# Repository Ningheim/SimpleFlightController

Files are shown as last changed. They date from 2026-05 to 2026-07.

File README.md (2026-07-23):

# SimpleFlightController



This is a USB-C powered 2-layer flight controller built around the STM32F722. It's 2S LiPo/Li-ion battery, a 6-axis IMU, a barometer, microSD logging, and two servo outputs.

## List of Materials

- MCU: STM32F722RET6
- IMU: ICM-20948 (SPI) — barometer: BME280 (I2C)
- Charger: BQ25887
- Power: TPS63070 buck-boost, LMR51430 buck
- microSD: 4-bit SD card slot
- J1/J3: servo/PWM headers
- J2: 2S battery screw terminal
- SW1 reset, SW2 boot, D1 status LED indicator
- 25MHz HSE + 32.768kHz LSE crystals
- Board: 50x55mm, 2-layer, KiCad 
- the hardware folder has the KiCad files. Run lcsc.py first to get parts KiCAD didn't have. This came from the hack club guide.

## Power architecture

```
2S Battery ----> TPS63070 ----> VSYS ----> LMR51430 ----> 3.3V rail

USB-C VBUS ----> BQ25887 Charger
```

## How To Make It Yourself

1. Run `lcsc.py` so the libraries resolve.
2. Open the .kicad_pro file in KiCad.
3. Export gerbers/drill/pick-and-place and send to JLCPCB for a quote.
4. Generate a BOM and assemble with a stencil, paste, and reflow.
5. Power up: 2S LIPO pack on the battery pad, `J2`.
6. Flash: hold `SW2`, reset with `SW1`, flash over `USB1`.

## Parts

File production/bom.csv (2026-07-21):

Designator | Footprint | Quantity | Value | LCSC Part #
C1, C18, C19, C20, C21, C26, C27, C28, C29, C30, C39 | 0402 | 11 | 100nF
C10, C11, C9 | 0805 | 3 | 22uF
C12, C13, C14, C3, C4, C6, C8 | 0402 | 7 | 10uF
C15 | 0402 | 1 | 2.2μF
C16, C17 | 0805 | 2 | 22μF
C2 | 0805 | 1 | 44uF
C22, C24 | 0402 | 2 | 100uF
C25 | 0402 | 1 | 2.2uF
C31, C32, C33, C34, C5 | 0402 | 5 | 1uF
C35, C36 | 0402 | 2 | 6.8pF
C37, C38 | 0402 | 2 | 20pF
C7 | 0805 | 1 | 47uF
CARD1 | TF-SMD_DM3CS-SF | 1 | DM3C-SF | C3177034
D1 | 0402 | 1 | LED
J1, J3 | PinHeader_2x03_P2.54mm_Vertical | 2 | Conn_01x03
J2 | TerminalBlock_Xinya_XY308-2.54-3P_1x03_P2.54mm_Horizontal | 1 | Screw_Terminal_01x03
L1 | 1008 | 1 | 1μH
L2 | L_APV_ANR4012 | 1 | 1.5μH
L3 | 1210 | 1 | 5.6μH
L4 | L0603 | 1 | FCM1608KF-601T03 | C141723
R1, R2 | 0201 | 2 | 5.1K
R10 | 0201 | 1 | 5.23k
R11 | 0201 | 1 | 383
R12 | 0201 | 1 | RCBSET
R13, R14, R15, R18, R19, R20, R21, R22, R23, R24, R4, R5, R6, R8 | 0201 | 14 | 10k
R16 | 0201 | 1 | 22.1k
R17 | 0201 | 1 | 100k
R3 | 0201 | 1 | 2.2k
R7 | 0201 | 1 | 300
R9 | 0201 | 1 | 30.1k
SW1, SW2 | SW-SMD_L3.9-W3.0-P4.45 | 2 | TS-1088-AR02016 | C720477
U1 | VQFN-15_L3.0-W2.5-P0.50-BL | 1 | TPS63070RNMR | C109322
U3 | QFN-24_L3.0-W3.0-P0.40-BL-EP | 1 | ICM-20948 | C726001
U4 | LGA-8_BME280_BL | 1 | BME280 | C92489
U5 | VQFN-24_L4.0-W4.0-P0.50-TL-EP2.7 | 1 | BQ25887RGET | C2862617
U6 | SOT-23-6_L2.9-W1.6-P0.95-LS2.8-BL | 1 | LMR51430XDDCR | C5185863
U7 | LQFP-64_10x10mm_P0.5mm | 1 | STM32F722RETx
USB1 | USB-C-SMD_TYPE-C-16PIN-2MD-073 | 1 | TYPE-C 16PIN 2MD | C2765186
X1 | CRYSTAL-SMD_4P-L3.2-W2.5-BL | 1 | X322525MOB4SI | C9006
X2 | FC-135R_L3.2-W1.5 | 1 | Q13FC1350000400 | C32346

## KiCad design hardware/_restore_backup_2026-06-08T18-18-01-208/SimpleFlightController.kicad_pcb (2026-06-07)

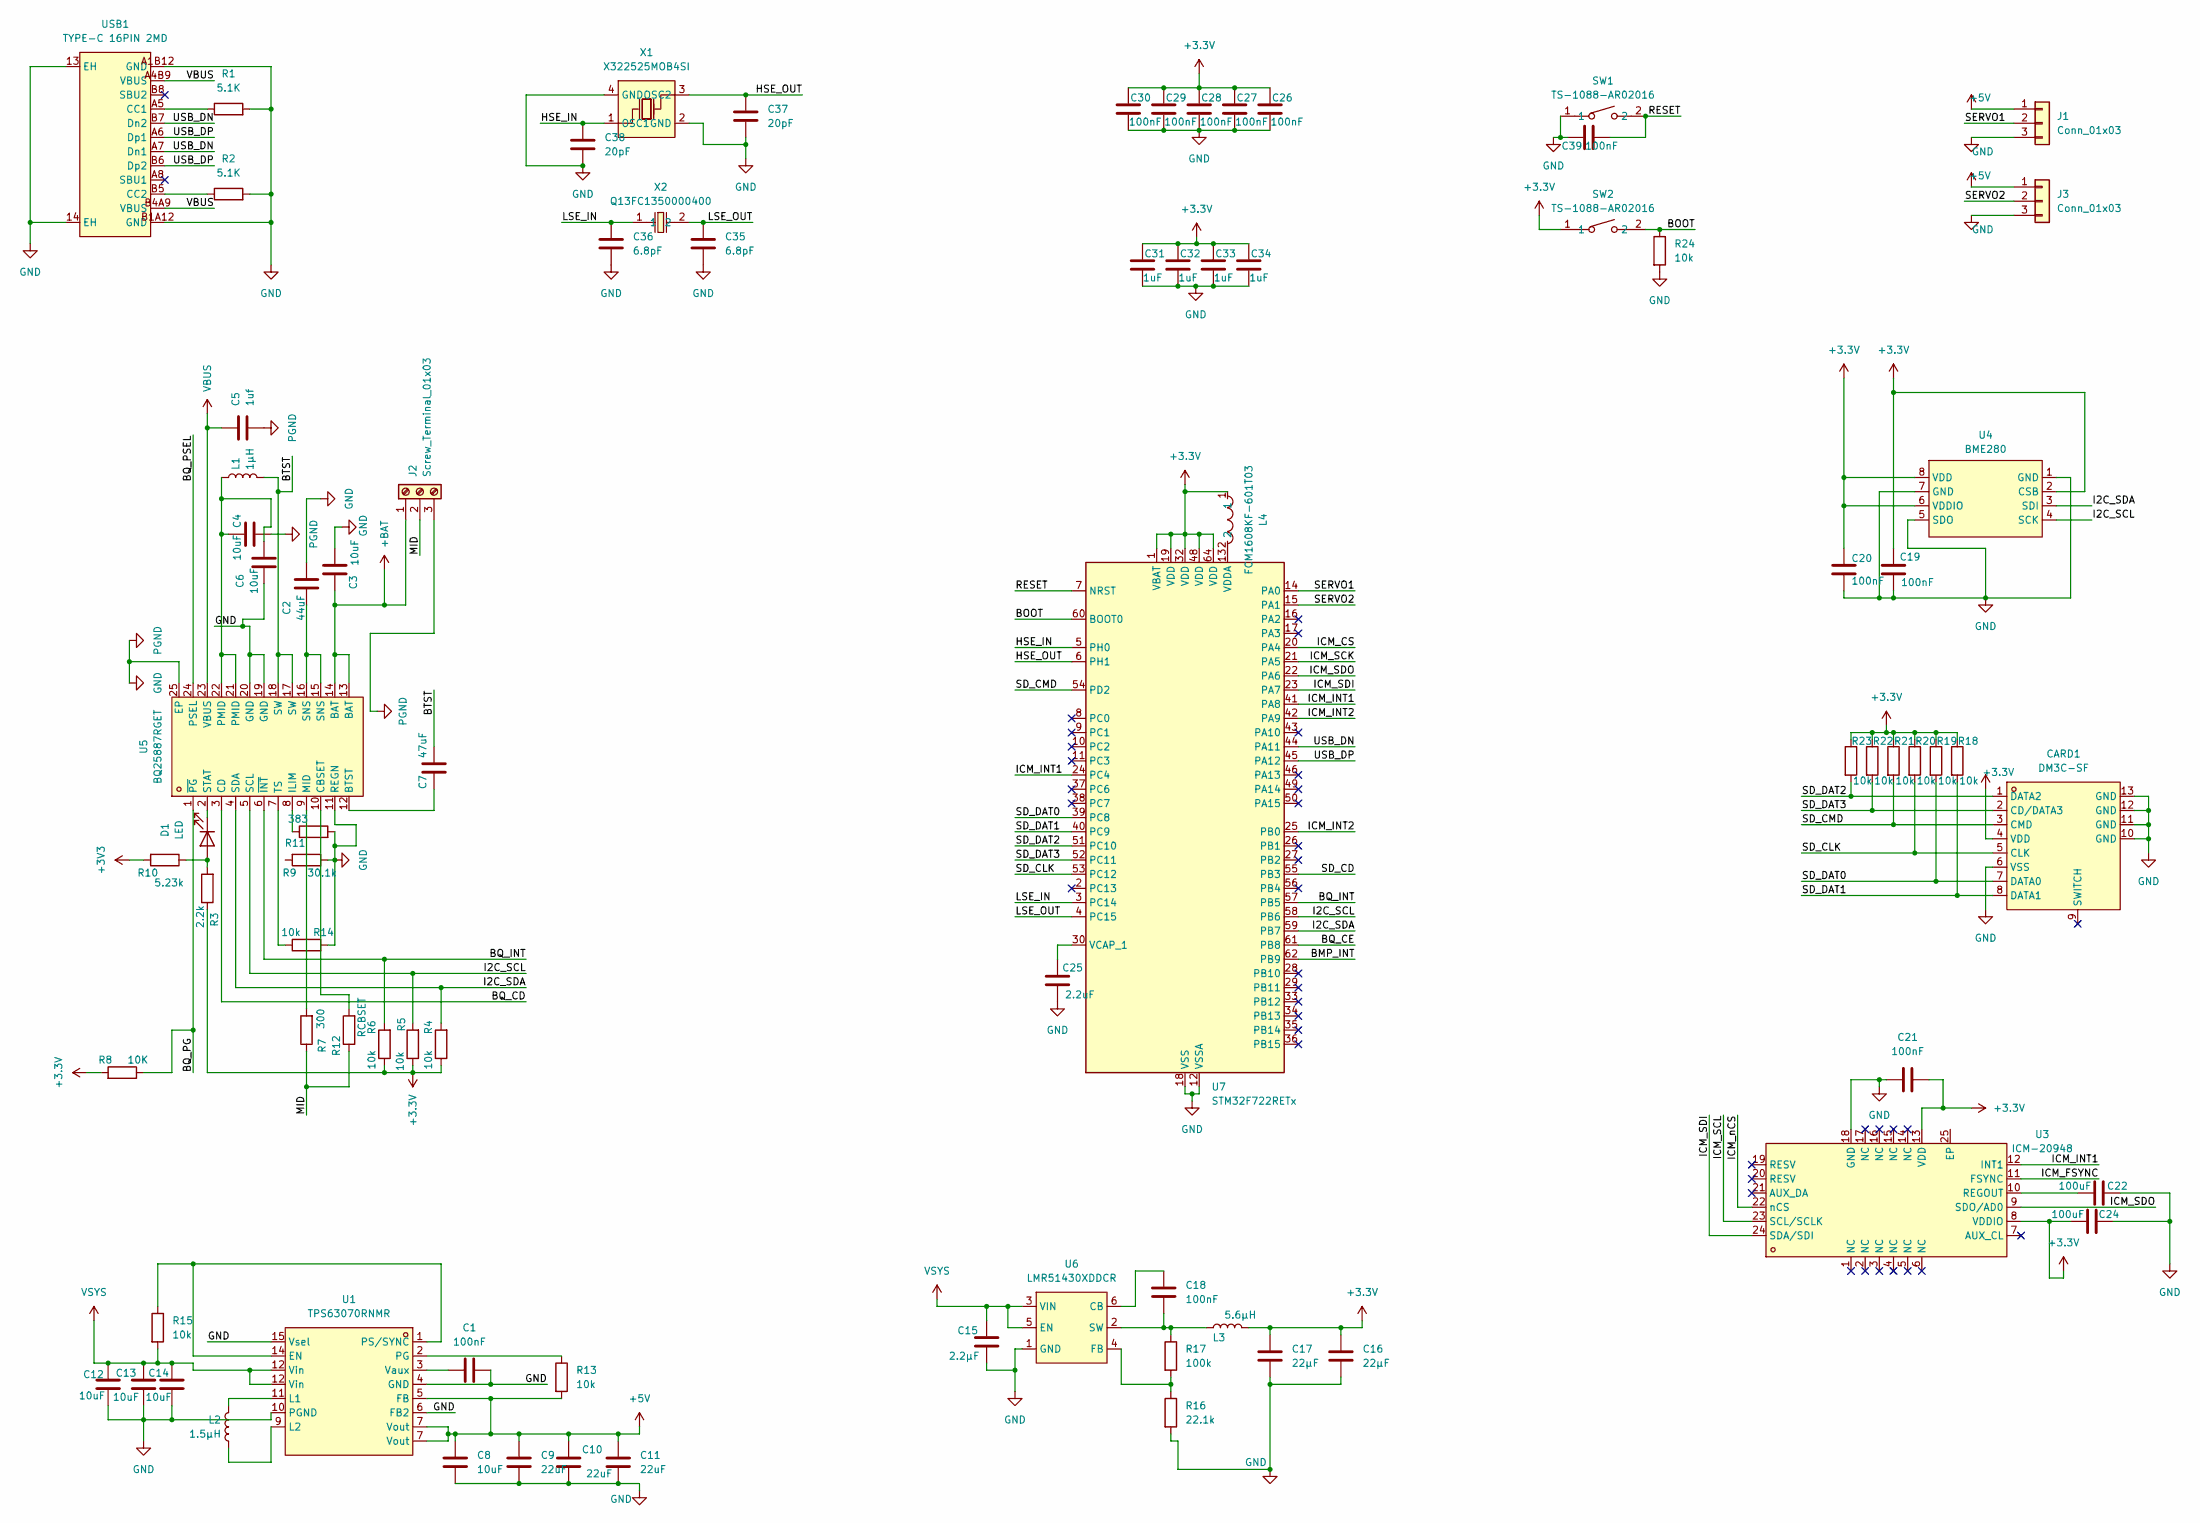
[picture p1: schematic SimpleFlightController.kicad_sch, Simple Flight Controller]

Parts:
C1, C18, C19, C20, C21, C26, C27, C28, C29, C30, C39: 100nF; C_0402_1005Metric
C2: 44uF; C_0805_2012Metric
C3, C4, C6, C8, C12, C13, C14: 10uF; C_0402_1005Metric
C5: 1uf; C_0402_1005Metric
C7: 47uF; C_0805_2012Metric
C9, C10, C11: 22uF; C_0805_2012Metric
C15: 2.2μF; C_0402_1005Metric
C16, C17: 22μF; C_0805_2012Metric
C22, C24: 100uF; C_0402_1005Metric
C25: 2.2uF; C_0402_1005Metric
C31, C32, C33, C34: 1uF; C_0402_1005Metric
C35, C36: 6.8pF; C_0402_1005Metric
C37, C38: 20pF; C_0402_1005Metric
CARD1: DM3C-SF; TF-SMD_DM3CS-SF; MPN DM3C-SF; LCSC Part C3177034
D1: LED; LED_0402_1005Metric
J1, J3: Conn_01x03; PinHeader_2x03_P2.54mm_Vertical
J2: Screw_Terminal_01x03; TerminalBlock_Xinya_XY308-2.54-3P_1x03_P2.54mm_Horizontal
L1: 1μH; L_1008_2520Metric
L2: 1.5μH; L_APV_ANR4012
L3: 5.6μH; L_1210_3225Metric
L4: FCM1608KF-601T03; L0603; MPN FCM1608KF-601T03; LCSC Part C141723
R1, R2: 5.1K; R_0201_0603Metric
R3: 2.2k; R_0201_0603Metric
R4, R5, R6, R13, R14, R15, R18, R19, R20, R21, R22, R23, R24: 10k; R_0201_0603Metric
R7: 300; R_0201_0603Metric
R8: 10K; R_0201_0603Metric
R9: 30.1k; R_0201_0603Metric
R10: 5.23k; R_0201_0603Metric
R11: 383; R_0201_0603Metric
R12: RCBSET; R_0201_0603Metric
R16: 22.1k; R_0201_0603Metric
R17: 100k; R_0201_0603Metric
SW1, SW2: TS-1088-AR02016; SW-SMD_L3.9-W3.0-P4.45; MPN TS-1088-AR02016; LCSC Part C720477
U1: TPS63070RNMR; VQFN-15_L3.0-W2.5-P0.50-BL; MPN TPS63070RNMR; LCSC Part C109322
U3: ICM-20948; QFN-24_L3.0-W3.0-P0.40-BL-EP; MPN ICM-20948; LCSC Part C726001
U4: BME280; LGA-8_BME280_BL; MPN BME280; LCSC Part C92489
U5: BQ25887RGET; VQFN-24_L4.0-W4.0-P0.50-TL-EP2.7; MPN BQ25887RGET; LCSC Part C2862617
U6: LMR51430XDDCR; SOT-23-6_L2.9-W1.6-P0.95-LS2.8-BL; MPN LMR51430XDDCR; LCSC Part C5185863
U7: STM32F722RETx; LQFP-64_10x10mm_P0.5mm
USB1: TYPE-C 16PIN 2MD; USB-C-SMD_TYPE-C-16PIN-2MD-073; MPN TYPE-C 16PIN 2MD(073); LCSC Part C2765186
X1: X322525MOB4SI; CRYSTAL-SMD_4P-L3.2-W2.5-BL; MPN X322525MOB4SI; LCSC Part C9006
X2: Q13FC1350000400; FC-135R_L3.2-W1.5; MPN Q13FC13500004; LCSC Part C32346

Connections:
+3.3V: C16.1, C17.1, C19.1, C20.1, C21.2, C24.1, C26.1, C27.1, C28.1, C29.1, C30.1, C31.1, C32.1, C33.1, C34.1, CARD1.4 (VDD), L3.2, L4.1, R3.1, R4.1, R5.1, R6.1, R8.2, R18.1, R19.1, R20.1, R21.1, R22.1, R23.1, SW2.1, U3.8 (VDDIO), U3.13 (VDD), U4.2 (CSB), U4.6 (VDDIO), U4.8 (VDD), U7.1 (VBAT), U7.19 (VDD), U7.32 (VDD), U7.48 (VDD), U7.64 (VDD)
+3V3: R10.2
+5V: C8.1, C9.1, C10.1, C11.1, J1.1, J3.1, R13.2, U1.5 (FB), U1.7 (Vout)
+BAT: C3.1, J2.1, U5.13 (BAT), U5.14 (BAT)
/BMP_INT: U7.62 (PB9)
/BOOT: R24.1, SW2.2, U7.60 (BOOT0)
/BQ_CD: U5.3 (CD)
/BQ_CE: U7.61 (PB8)
/BQ_INT: R6.2, U5.6 (~INT), U7.57 (PB5)
/BQ_PG: R8.1, U5.1 (~PG)
/BQ_PSEL: U5.24 (PSEL)
/BTST: C7.2, L1.2, U5.17 (SW), U5.18 (SW)
/HSE_IN: C38.1, U7.5 (PH0), X1.1 (OSC1)
/HSE_OUT: C37.1, U7.6 (PH1), X1.3 (OSC2)
/I2C_SCL: R5.2, U4.4 (SCK), U5.5 (SCL), U7.58 (PB6)
/I2C_SDA: R4.2, U4.3 (SDI), U5.4 (SDA), U7.59 (PB7)
/ICM_CS: U7.20 (PA4)
/ICM_FSYNC: U3.11 (FSYNC)
/ICM_INT1: U3.12 (INT1), U7.24 (PC4), U7.41 (PA8)
/ICM_INT2: U7.25 (PB0), U7.42 (PA9)
/ICM_SCK: U7.21 (PA5)
/ICM_SCL: U3.23 (SCL/SCLK)
/ICM_SDI: U3.24 (SDA/SDI), U7.23 (PA7)
/ICM_SDO: U3.9 (SDO/AD0), U7.22 (PA6)
/ICM_nCS: U3.22 (nCS)
/LSE_IN: C36.1, U7.3 (PC14), X2.1
/LSE_OUT: C35.1, U7.4 (PC15), X2.2
/MID: J2.2, R7.1, R12.1
/RESET: C39.2, SW1.2, U7.7 (NRST)
/SD_CD: U7.55 (PB3)
/SD_CLK: CARD1.5 (CLK), R20.2, U7.53 (PC12)
/SD_CMD: CARD1.3 (CMD), R21.2, U7.54 (PD2)
/SD_DAT0: CARD1.7 (DATA0), R19.2, U7.39 (PC8)
/SD_DAT1: CARD1.8 (DATA1), R18.2, U7.40 (PC9)
/SD_DAT2: CARD1.1 (DATA2), R23.2, U7.51 (PC10)
/SD_DAT3: CARD1.2 (CD/DATA3), R22.2, U7.52 (PC11)
/SERVO1: J1.2, U7.14 (PA0)
/SERVO2: J3.2, U7.15 (PA1)
/USB_DN: U7.44 (PA11), USB1.A7 (Dn1), USB1.B7 (Dn2)
/USB_DP: U7.45 (PA12), USB1.A6 (Dp1), USB1.B6 (Dp2)
GND: C1.1, C2.2, C3.2, C4.2, C5.2, C6.1, C8.2, C9.2, C10.2, C11.2, C12.2, C13.2, C14.2, C15.2, C16.2, C17.2, C19.2, C20.2, C21.1, C22.2, C24.2, C25.2, C26.2, C27.2, C28.2, C29.2, C30.2, C31.2, C32.2, C33.2, C34.2, C35.2, C36.2, C37.2, C38.2, C39.1, CARD1.6 (VSS), CARD1.10 (GND), CARD1.11 (GND), CARD1.12 (GND), CARD1.13 (GND), J1.3, J2.3, J3.3, R1.2, R2.2, R9.1, R11.2, R14.2, R16.2, R24.2, SW1.1, U1.4 (GND), U1.6 (FB2), U1.10 (PGND), U1.15 (Vsel), U3.18 (GND), U4.1 (GND), U4.5 (SDO), U4.7 (GND), U5.11 (REGN), U5.19 (GND), U5.20 (GND), U5.25 (EP), U6.1 (GND), U7.12 (VSSA), U7.18 (VSS), U7.31 (VSS), U7.47 (VSS), U7.63 (VSS), USB1.13 (EH), USB1.14 (EH), USB1.A1B12 (GND), USB1.B1A12 (GND), X1.2 (GND), X1.4 (GND)
unnamed: C2.1, U5.15 (SNS), U5.16 (SNS)
unnamed: C4.1, C6.2, L1.1, U5.21 (PMID), U5.22 (PMID)
unnamed: D1.2 (A), R3.2, R10.1
unnamed: D1.1 (K), U5.2 (STAT)
unnamed: R15.1, U1.1 (PS/SYNC), U1.14 (EN)
unnamed: L2.1, U1.11 (L1)
unnamed: L2.2, U1.9 (L2)
unnamed: R13.1, U1.2 (PG)
unnamed: C1.2, U1.3 (Vaux)
unnamed: C22.1, U3.10 (REGOUT)
unnamed: C7.1, U5.12 (BTST)
unnamed: R12.2, U5.10 (CBSET)
unnamed: R11.1, U5.8 (ILIM)
unnamed: R7.2, U5.9 (MID)
unnamed: R14.1, U5.7 (TS)
unnamed: C18.1, U6.6 (CB)
unnamed: R16.1, R17.2, U6.4 (FB)
unnamed: C18.2, L3.1, R17.1, U6.2 (SW)
unnamed: C25.1, U7.30 (VCAP_1)
unnamed: L4.2, U7.13 (VDDA)
unnamed: R1.1, USB1.A5 (CC1)
unnamed: R2.1, USB1.B5 (CC2)
VBUS: C5.1, U5.23 (VBUS), USB1.A4B9 (VBUS), USB1.B4A9 (VBUS)
VSYS: C12.1, C13.1, C14.1, C15.1, R15.2, U1.12 (Vin), U6.3 (VIN), U6.5 (EN)

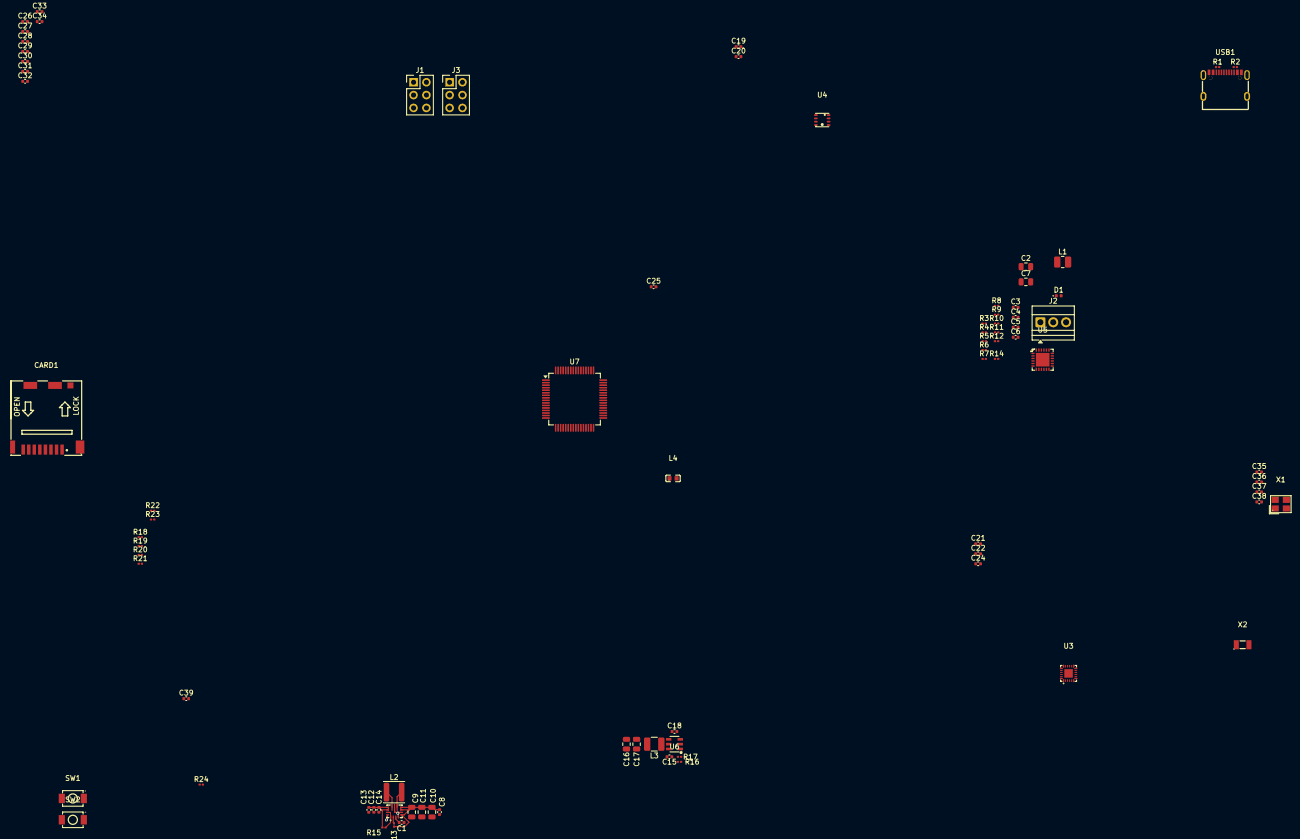
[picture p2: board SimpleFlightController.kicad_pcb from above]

Board: 2 copper layers, 82 parts (0 on the bottom side), 54 nets.

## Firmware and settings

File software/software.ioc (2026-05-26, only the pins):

Mcu.UserName=STM32F722RETx
PA0-WKUP.Signal=S_TIM2_CH1_ETR
PA1.Signal=S_TIM2_CH2
PA11.Signal=USB_OTG_FS_DM
PA12.Signal=USB_OTG_FS_DP
PA4.Signal=SPI1_NSS
PA5.Signal=SPI1_SCK
PA6.Signal=SPI1_MISO
PA7.Signal=SPI1_MOSI
PB0.Signal=GPXTI0
PB3.Signal=GPIO_Input
PB5.Signal=GPXTI5
PB6.Signal=I2C1_SCL
PB7.Signal=I2C1_SDA
PB8.Signal=GPIO_Output
PB9.Signal=GPXTI9
PC10.Signal=SDMMC1_D2
PC11.Signal=SDMMC1_D3
PC12.Signal=SDMMC1_CK
PC14-OSC32_IN.Signal=RCC_OSC32_IN
PC15-OSC32_OUT.Signal=RCC_OSC32_OUT
PC4.Signal=GPXTI4
PC8.Signal=SDMMC1_D0
PC9.Signal=SDMMC1_D1
PD2.Signal=SDMMC1_CMD
PH0-OSC_IN.Signal=RCC_OSC_IN
PH1-OSC_OUT.Signal=RCC_OSC_OUT

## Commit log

2026-05-21 Battery Charger 80% Done
    I ended up finishing wiring all the pins except for the battery related ones, I'll finish those tomorrow and I'll move on to the sensors.
    [SimpleFlightController.kicad_sch]
2026-05-23 5/22/2026: Finished Regulator, Sensor, and Tracker
    Everything went smoothly, using the datasheets for so long has given me a better understanding on what each symbol means/does.
    [SimpleFlightController.kicad_sch]
2026-05-26 Finished Schematic
    [SimpleFlightController.kicad_sch]
2026-05-28 PCB Footprints
    [SimpleFlightController.kicad_pcb, SimpleFlightController.kicad_sch]
2026-06-07 PCB Routing
    [SimpleFlightController.kicad_pcb, SimpleFlightController.kicad_sch]
2026-06-10 PCB Layout Almost Final
    [SimpleFlightController.kicad_pcb, SimpleFlightController.kicad_sch]
2026-07-21 Finishing Touches
    [SimpleFlightController.kicad_pcb, bom.csv, designators.csv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]
2026-07-22 Final Touches
    [SimpleFlightController.kicad_pcb]
